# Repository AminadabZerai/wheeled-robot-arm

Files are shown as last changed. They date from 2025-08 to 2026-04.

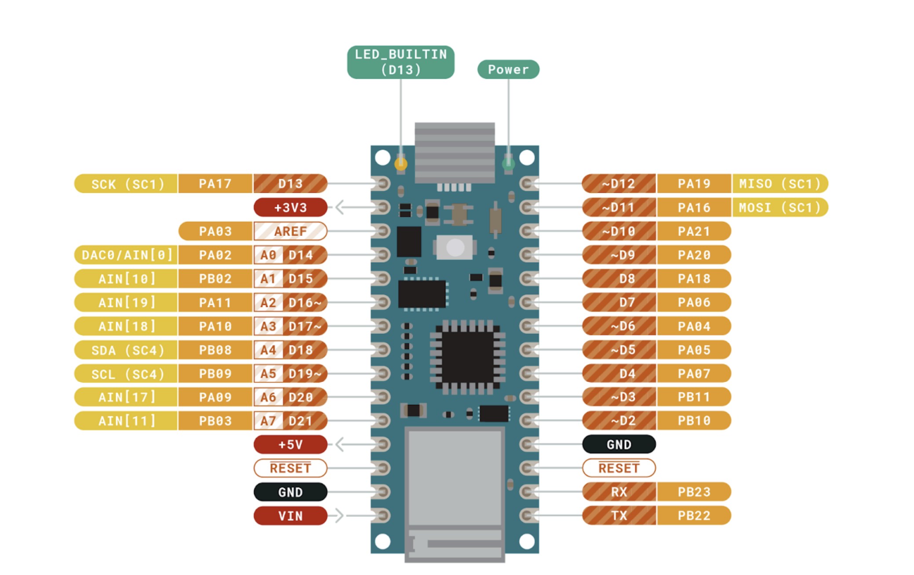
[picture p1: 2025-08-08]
Roadmap and Reference/Pinouts/Screenshot 2025-07-16 204437.jpg

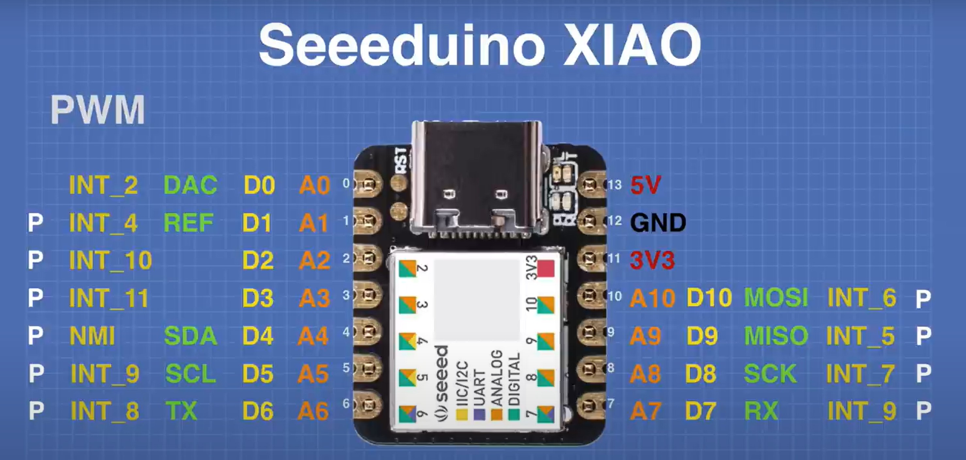
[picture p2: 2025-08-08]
Roadmap and Reference/Pinouts/Screenshot 2025-07-22 153515.jpg

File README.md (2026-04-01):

# wheeled-robot-arm

Wheeled robot with manipulator arm — ROS 2, Arduino, Raspberry Pi

A modular robotics platform combining a 4-wheel mecanum base with an articulated
manipulator arm. Built using Raspberry Pi, ROS 2, Arduino Nano 33 IoT, and custom
electronics. Designed for research, education, and portfolio development.

## Table of Contents

- [About](#about)
- [System Architecture](#system-architecture)
- [Project Roadmap](#project-roadmap)
- [Hardware](#hardware)
- [Software](#software)
- [Repository Structure](#repository-structure)
- [Getting Started](#getting-started)
- [Documentation](#documentation)
- [Contributing](#contributing)
- [License](#license)

## About

This project aims to design and build a wheeled mobile robot equipped with a
manipulator arm. It combines mechanical design, electronics, embedded systems,
and high-level control using ROS 2.

The firmware follows a component-based architecture — each hardware subsystem
(IMU, encoders, motors, PID) is isolated into its own driver module with a
clean API, making the system testable, swappable, and maintainable.

## System Architecture
```
┌─────────────────────────────────────┐
│         Raspberry Pi (ROS 2)        │
│   Navigation · Planning · Comms     │
└──────────────┬──────────────────────┘
               │ Serial / USB
┌──────────────▼──────────────────────┐
│       Arduino Nano 33 IoT          │
│  Main controller — 100Hz loop      │
│                                     │
│  ┌─────────┐ ┌──────────────────┐  │
│  │ LSM6DS3 │ │   TCA9548A Mux   │  │
│  │  IMU    │ │   ┌──┐┌──┐┌──┐┌──┐ │
│  └─────────┘ │   │E1││E2││E3││E4│ │
│              │   └──┘└──┘└──┘└──┘ │
│              │   AS5600 Encoders  │  │
│              └──────────────────────┘│
│  ┌──────────────────────────────┐   │
│  │  TB6612FNG Motor Drivers ×2  │   │
│  │  4× DC Motors (7.4V LiPo)   │   │
│  └──────────────────────────────┘   │
└─────────────────────────────────────┘
```

**Key design decisions:**
- Single MCU (Arduino Nano 33 IoT) controls all 4 wheels instead of per-wheel MCUs
- TCA9548A I2C multiplexer allows 4× AS5600 encoders on the same bus (same address 0x36)
- IMU (LSM6DS3) shares the I2C bus for orientation sensing
- PID + feedforward velocity control runs at 50 Hz per motor
- MATLAB tooling for offline calibration and sensor characterization

## Project Roadmap

### ✅ Section 1: Motor, Encoder, and Odometry Setup
- [x] Power system setup (7.4V LiPo, buck converters)
- [x] Mechanical assembly and wiring validation
- [x] AS5600 encoder integration via TCA9548A I2C mux
- [x] TB6612FNG motor driver wiring (2× drivers, 4 motors)
- [x] PID + feedforward velocity control (tuned, proven baseline)
- [x] Basic serial command interface (`f,150` / `r,90`)

### 🔄 Section 1.5: Firmware Refactoring & Sensor Characterization *(current)*
- [x] IMU driver extraction (`lib/IMU/`)
- [x] LSM6DS3 calibration and characterization (PASS — see journal)
- [x] MATLAB real-time plotter, 3D visualizer, and analysis tooling
- [x] Development journal established (`docs/journal.md`)
- [ ] Fix sampling jitter (interrupt-driven reads)
- [ ] AS5600 driver refactoring to match IMU module pattern
- [ ] Motor/PID module extraction
- [ ] Config/pin definitions centralized (`include/config.h`)
- [ ] On-board complementary filter for orientation

### 🔜 Section 2: Motion Control & Odometry
- [ ] Mecanum kinematic model (wheel velocities ↔ robot twist)
- [ ] Odometry estimation from encoders + IMU fusion
- [ ] Serial protocol for ROS 2 bridge (velocity commands + odom feedback)

### 🔜 Section 3: Manipulator Arm Integration
- [ ] Arm kinematics and mechanical design
- [ ] Servo/stepper driver electronics
- [ ] Dedicated controller or shared bus for arm joints
- [ ] ROS 2 nodes for arm control and planning

### 🔜 Section 4: High-Level Integration
- [ ] Raspberry Pi ROS 2 orchestration
- [ ] Autonomous and manual control modes
- [ ] System-level testing and refinement

## Hardware

| Component | Role | Qty |
|---|---|-----|
| Arduino Nano 33 IoT | Main MCU (3.3V logic) | 1 |
| Raspberry Pi | High-level ROS 2 control | 1 |
| AS5600 | 12-bit magnetic encoder | 4 |
| TCA9548A | I2C multiplexer | 1 |
| TB6612FNG | Dual H-bridge motor driver | 2 |
| DC Motors | Mecanum wheels, 7.4V | 4 |
| LiPo Battery | 7.4V 2S | 1 |
| Buck Converters | Voltage regulation | as needed |
| 3D Printed Parts | Brackets, mounts, chassis | various |

## Software

**Firmware (Arduino)**
- Modular C/C++ drivers in `lib/` (IMU, AS5600, MotorWheel, PID)
- 100 Hz deterministic main loop
- PID + feedforward velocity control with anti-windup
- Machine-readable CSV telemetry output

**MATLAB Tooling**
- Real-time data acquisition with infinite streaming and CSV export
- 3D orientation visualization with complementary filter
- Post-capture statistical analysis (noise, PSD, bias, pass/fail)

**ROS 2 (planned)**
- Velocity command interface
- Odometry publisher
- Arm control nodes

## Repository Structure
```
WHEELED-ROBOT-ARM/
├── src/
│   └── main.cpp              # Main firmware
├── include/
│   └── config.h              # Pin definitions and constants
├── lib/
│   ├── IMU/                  # LSM6DS3 driver
│   ├── AS5600/               # Magnetic encoder driver
│   ├── MotorWheel/           # Motor control abstraction
│   ├── PID/                  # PID controller
│   └── MoveBase/             # Kinematics and motion
├── matlab/
│   ├── imu_calibration_and_data.m
│   ├── imu_3d_visualization.m
│   ├── imu_analysis.m
│   └── data/                 # CSV captures
├── docs/
│   └── journal.md                        # Development journal
    └── zerillio_procedures.md            # General Procedure to boot the raspberry pi 3
├── 3D Files/                             # CAD and printable parts
├── Datasheets/                           # Component datasheets
├── ros2_ws/                              # ROS 2 workspace (future)
├── platformio.ini
├── LICENSE
└── README.md
```

## Getting Started

### Prerequisites
- [PlatformIO](https://platformio.org/) (firmware build and upload)
- MATLAB R2020b+ with Signal Processing Toolbox (analysis scripts)
- Arduino Nano 33 IoT board support

### Flash the firmware
```bash
cd WHEELED-ROBOT-ARM
pio run -t upload
```

### Run MATLAB live plotter
1. Connect Arduino via USB
2. Update `port` in the script to match your COM port
3. Run `imu_calibration_and_data.m`
4. Close the figure window to stop — CSV saves automatically

## Documentation

See [`docs/journal.md`](./docs/journal.md) for detailed development logs including
sensor characterization results, architecture decisions, and test data.

Additional resources in [`Datasheets/`](./Datasheets) and
[`Roadmap and References/`](./Roadmap%20and%20References).

## Contributing

Contributions, ideas, and bug reports are welcome.
Please open an Issue or submit a Pull Request.

## License

This project is licensed under the MIT License. See [LICENSE](./LICENSE) for details.

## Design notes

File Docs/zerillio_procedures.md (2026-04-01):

# Zerillio - Raspberry Pi 3 B+ Quick Reference

## Connection Info

- **Hostname:** zerillio.local
- **IP (hotspot):** check with `arp -a` from your PC (changes each time)
- **Username:** pi3
- **SSH command:** `ssh pi3@zerillio.local` or `ssh pi3@<IP_ADDRESS>`

---

## Starting Up

1. Make sure your phone hotspot is ON and broadcasting
2. Plug in the power cable to the Pi (there is no power button)
3. Wait ~2 minutes for boot + Wi-Fi connection
4. Check your phone — it should show a new connected device
5. From your PC (on the same hotspot), open Tabby or PowerShell:
   ```
   ssh pi3@zerillio.local
   ```
6. If hostname doesn't resolve:
   ```
   arp -a
   ```
   Find the Pi's IP and connect with `ssh pi3@<IP>`

---

## Shutting Down (Graceful)

Always shut down gracefully to avoid SD card corruption:

```
sudo shutdown -h now
```

Wait about 10 seconds until the green LED stops blinking, then unplug the power cable.

### Other Shutdown Options

| Command | What it does |
|---|---|
| `sudo shutdown -h now` | Shutdown immediately |
| `sudo shutdown -h +5` | Shutdown in 5 minutes |
| `sudo poweroff` | Same as shutdown -h now |
| `sudo reboot` | Restart the Pi |

---

## NEVER DO THIS

- **Never just unplug the power cable** while the Pi is running — this can corrupt the SD card and break your OS/ROS installation

---

## Useful Commands Once Connected

| Command | What it does |
|---|---|
| `htop` | Monitor CPU/RAM usage |
| `df -h` | Check disk space |
| `vcgencmd measure_temp` | Check CPU temperature |
| `tmux` | Start a persistent terminal session |
| `tmux attach` | Reattach to a tmux session after disconnect |
| `ros2 doctor` | Check ROS 2 health |
| `source ~/.bashrc` | Reload shell config |

---

## Wi-Fi Networks Configured

1. **ABI24** (phone hotspot) — primary, SSH works
2. **eduroam** (Polito) — internet only, SSH blocked by network

---

## ROS 2 Info

- **Distro:** Jazzy Jalisco
- **Workspace:** ~/ros2_ws/src
- **Domain ID:** 42
- **Robot name:** zerillio

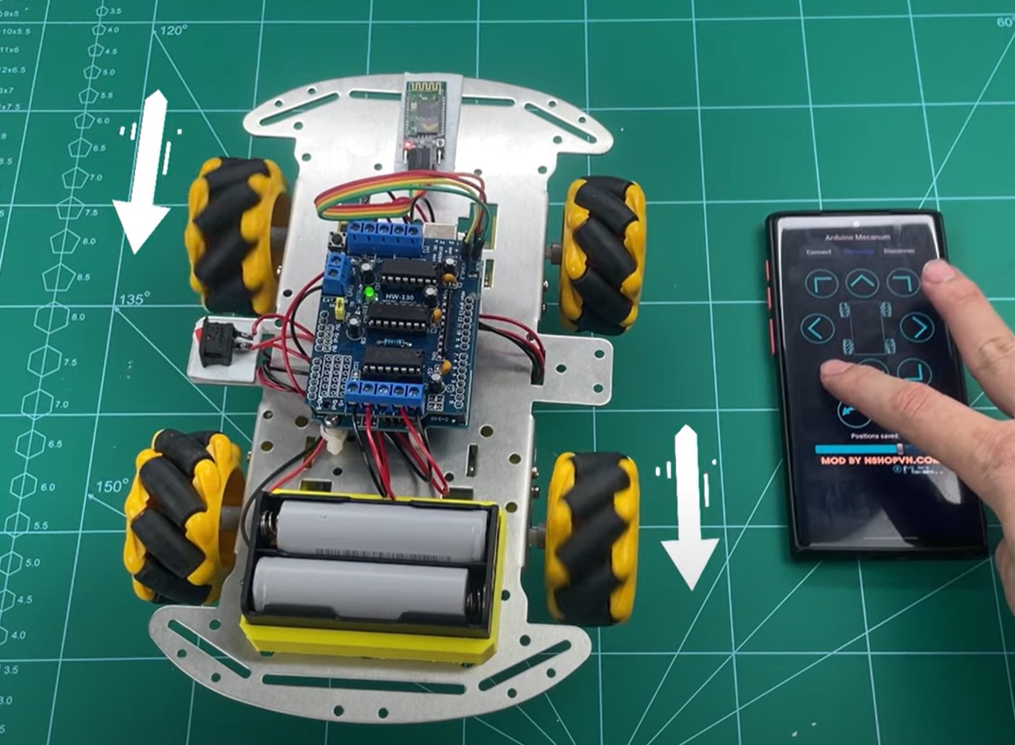
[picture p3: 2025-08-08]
Roadmap and Reference/Mecanum_Wheel_Control/Mecanum_Wheel_DIAG_LB.jpg

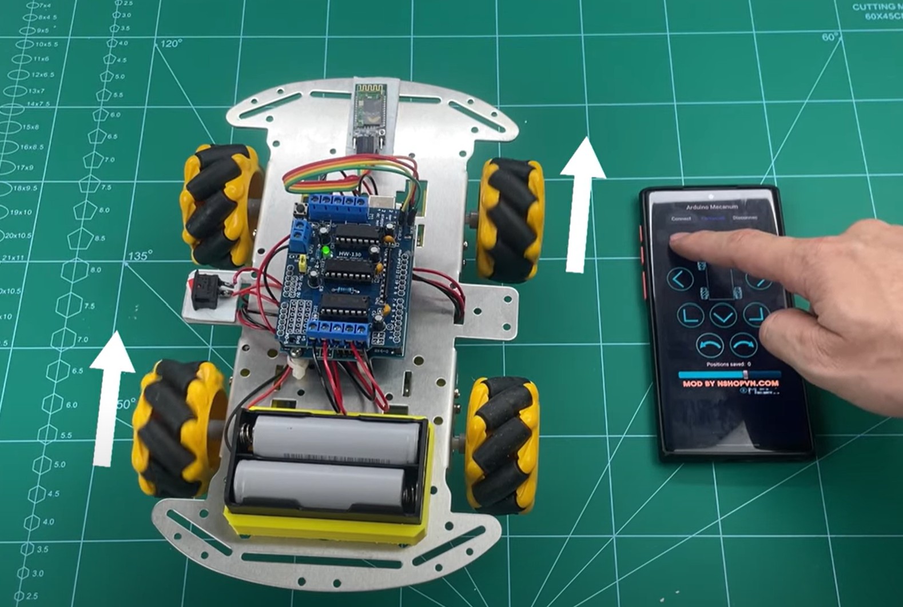
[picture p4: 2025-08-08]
Roadmap and Reference/Mecanum_Wheel_Control/Mecanum_Wheel_DIAG_LT.jpg

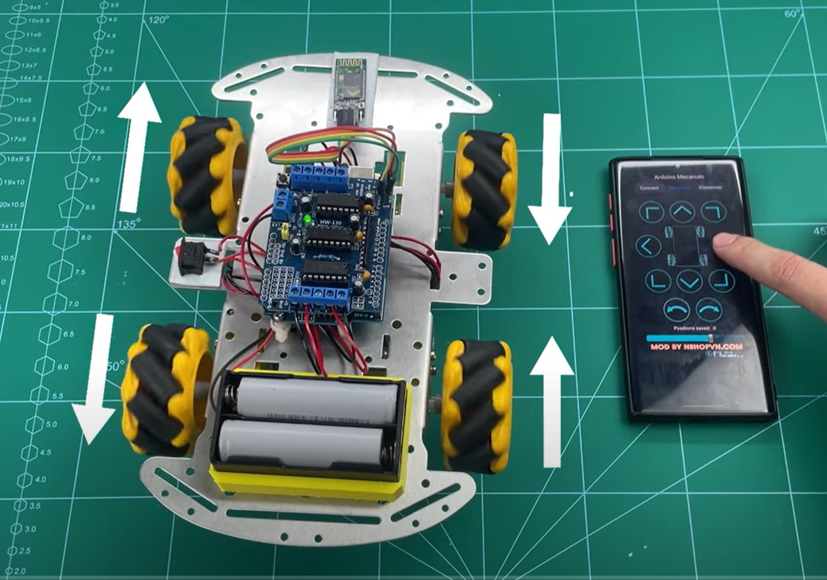
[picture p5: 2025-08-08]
Roadmap and Reference/Mecanum_Wheel_Control/Mecanum_Wheel_SW_R.jpg

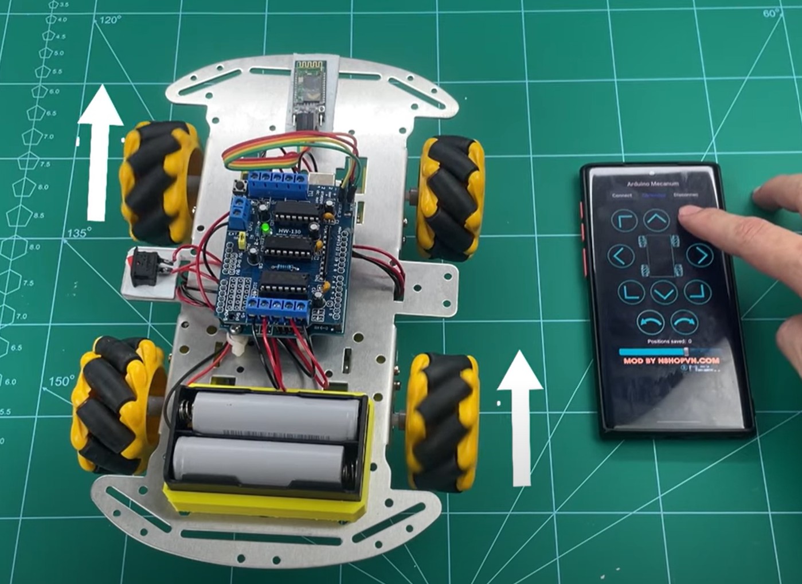
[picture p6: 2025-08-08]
Roadmap and Reference/Mecanum_Wheel_Control/Mecanum_Wheel_DIAG_RT.jpg

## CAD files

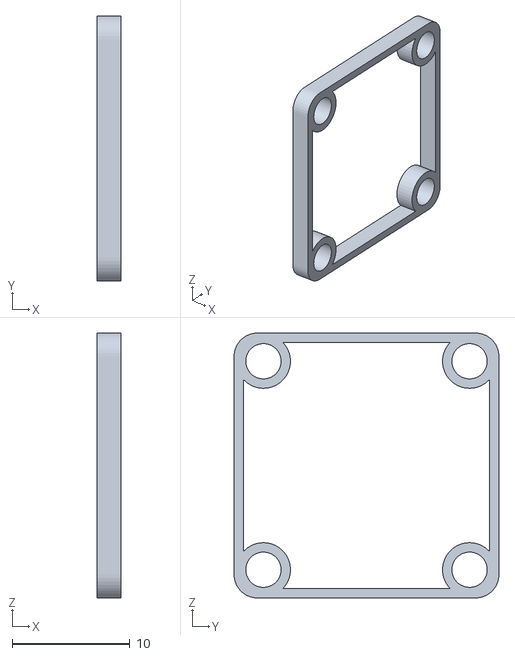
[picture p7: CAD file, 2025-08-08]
3D Files/Final_Brack_Assembly_Iteration_1 - AS5600_Bracket_Iteration_1-1.STL
2.00 x 22.5 x 22.5

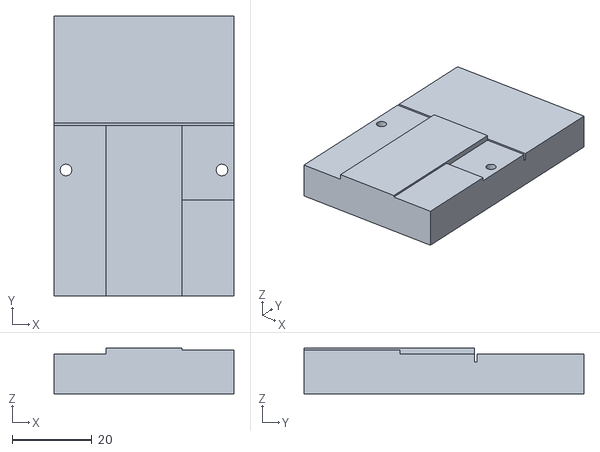
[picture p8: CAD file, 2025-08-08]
3D Files/Final_Brack_Assembly_Iteration_1 - Bracket_Base_Iteration_4-1.STL
45.0 x 70.0 x 11.5

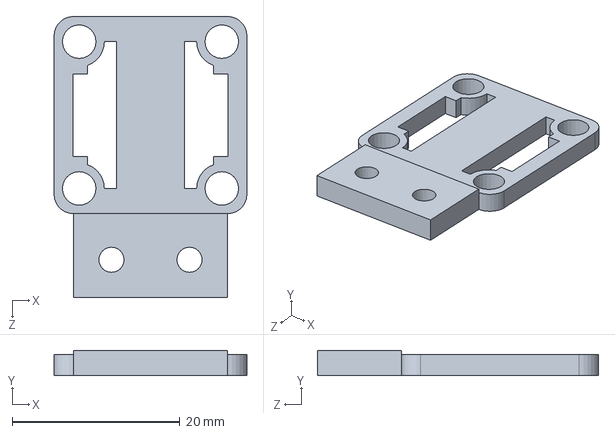
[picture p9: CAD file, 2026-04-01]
3D Files/AS5600_Bracket_Iteration_12.SLDPRT
23.0 x 3.00 x 33.5 mm

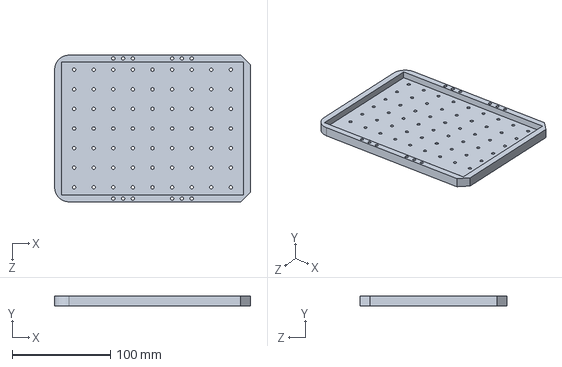
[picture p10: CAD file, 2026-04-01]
3D Files/Chasis_Holed_Iteration_1.SLDPRT
200.0 x 10.0 x 150.0 mm

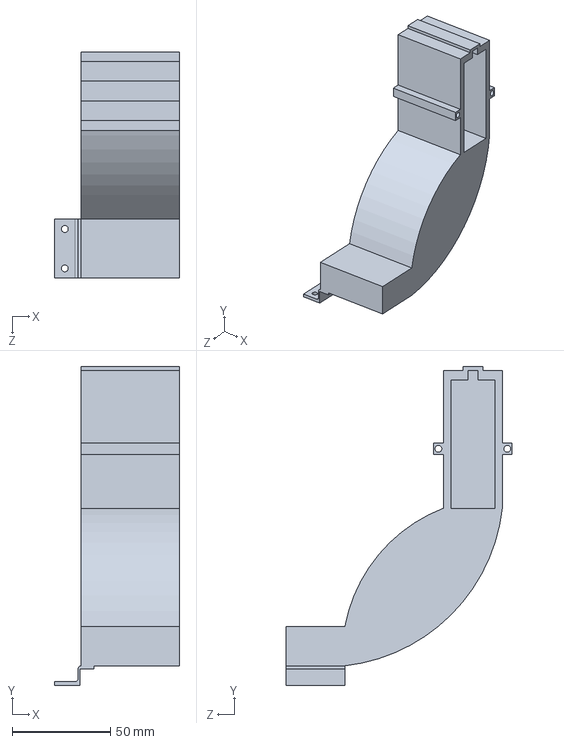
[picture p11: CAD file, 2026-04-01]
3D Files/Wheel_Leg_Iteration_1.SLDPRT
63.5 x 162.0 x 115.0 mm

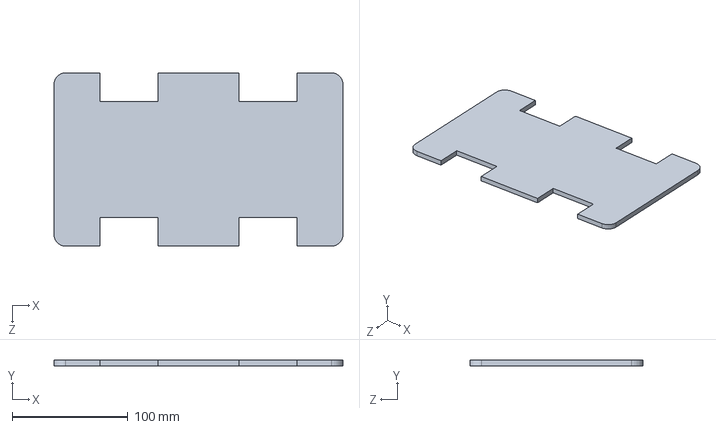
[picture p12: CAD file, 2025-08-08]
3D Files/Chasis_Iteration_1.SLDPRT
250.0 x 5.00 x 150.0 mm

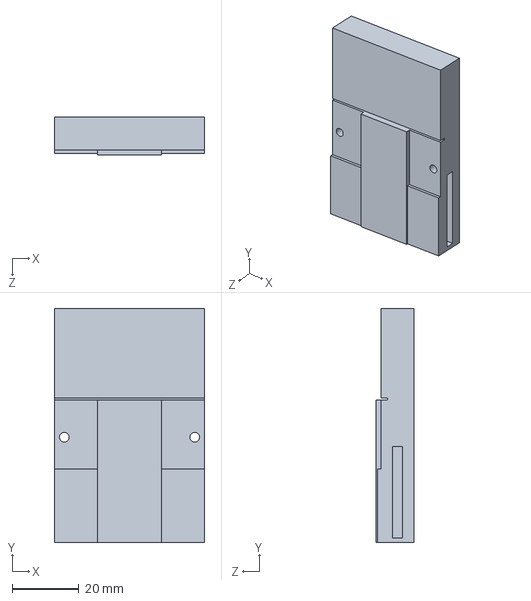
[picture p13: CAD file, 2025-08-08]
3D Files/Bracket_Base_Iteration_8.SLDPRT
45.0 x 70.0 x 11.5 mm

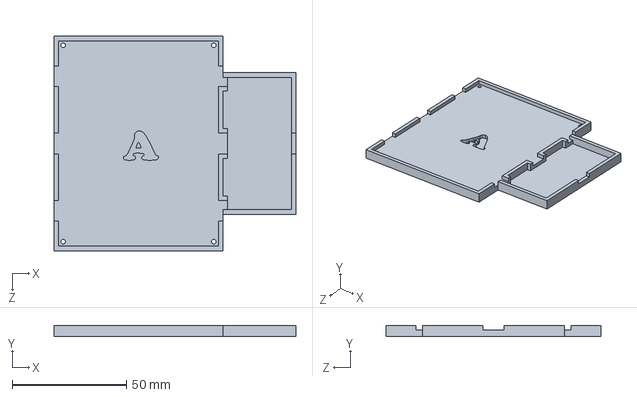
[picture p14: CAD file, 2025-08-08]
3D Files/Power_Management.SLDPRT
106.0 x 5.00 x 94.0 mm

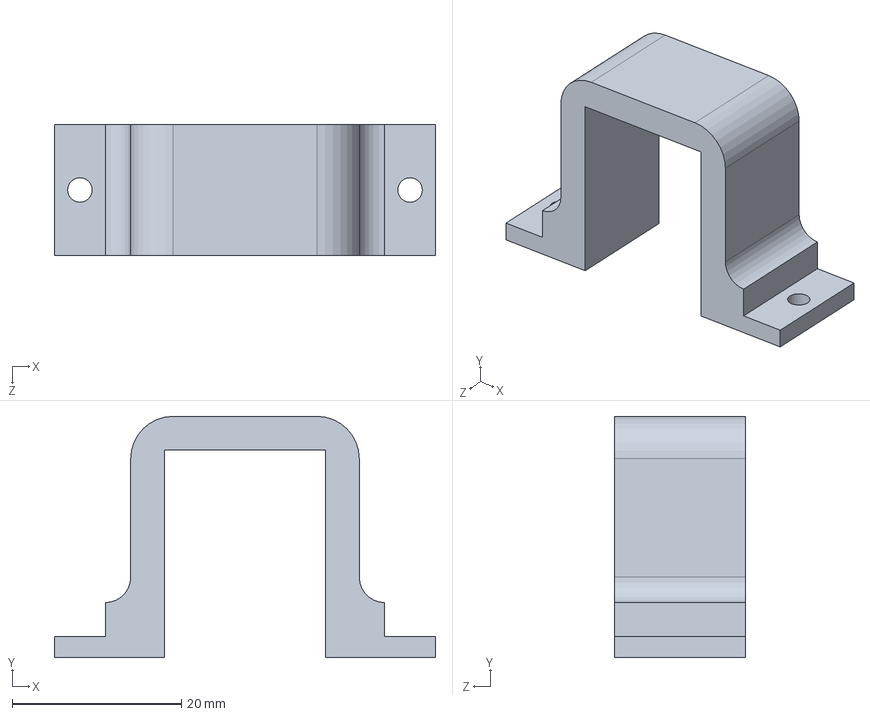
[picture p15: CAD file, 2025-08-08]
3D Files/Motor_Bracket_Iteration_8.SLDPRT
45.0 x 28.5 x 15.5 mm

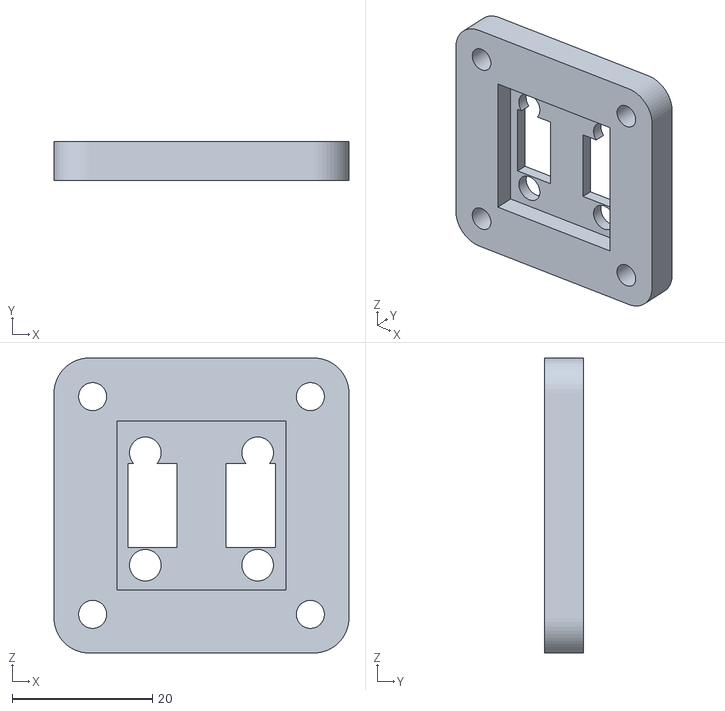
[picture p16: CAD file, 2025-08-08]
3D Files/AS5600Mount_nema17.stl
42.0 x 5.50 x 42.0

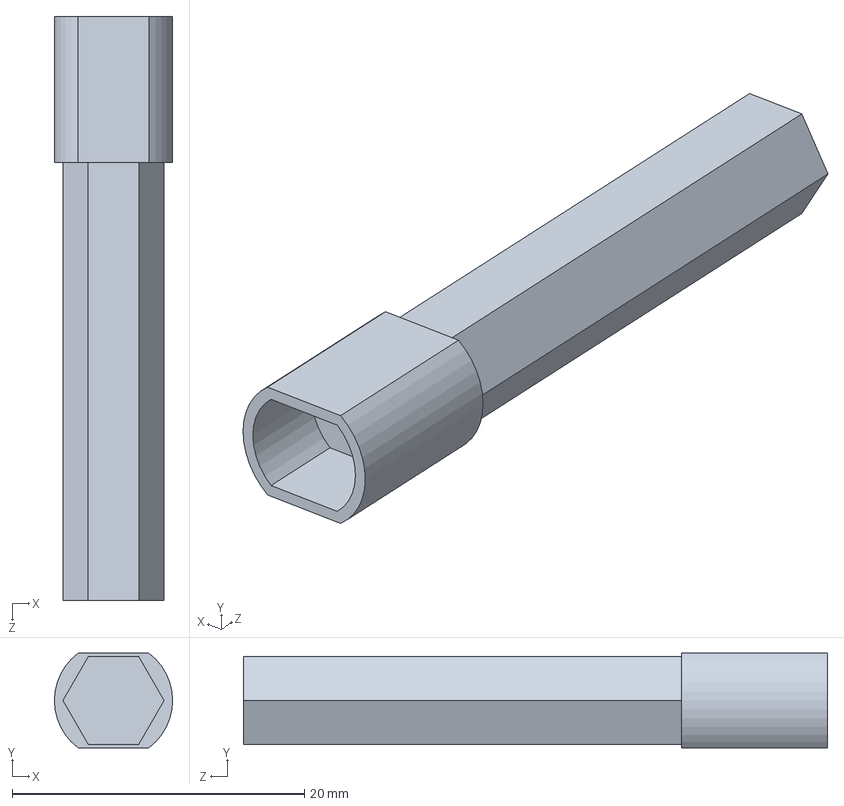
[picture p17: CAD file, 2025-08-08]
3D Files/Wheel_shaft_Iteration_5.SLDPRT
8.10 x 6.50 x 40.0 mm

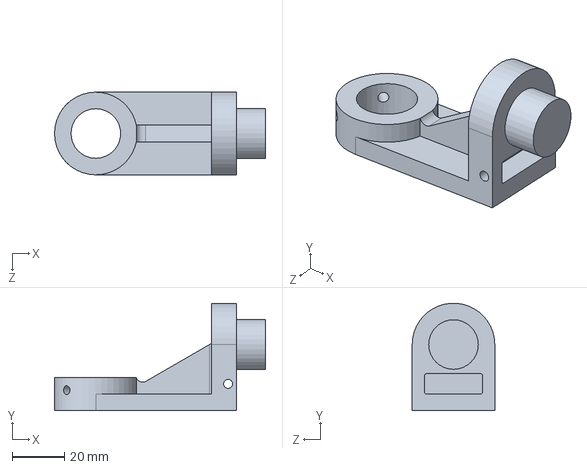
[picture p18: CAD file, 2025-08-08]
3D Files/cswa_practice_YT_1.SLDPRT
81.0 x 41.2 x 31.8 mm

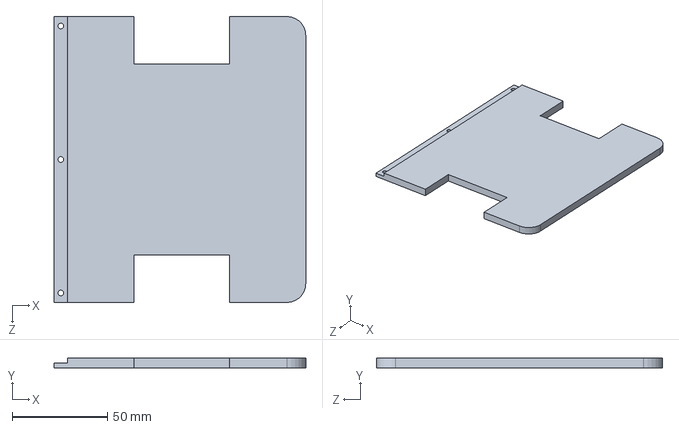
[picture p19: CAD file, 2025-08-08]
3D Files/Chasis_Iteration_2_prt_1.SLDPRT
132.0 x 5.00 x 150.0 mm

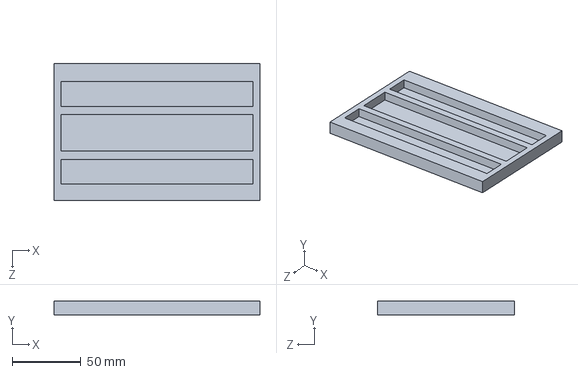
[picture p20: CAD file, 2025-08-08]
3D Files/Base_Plank.SLDPRT
150.0 x 10.0 x 100.0 mm

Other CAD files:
3D Files/Final_Brack_Assembly_Iteration_1.SLDASM
3D Files/AS5600_Bracket_Iteration_6.SLDPRT
3D Files/Motor_Bracket_Iteration_2.SLDPRT
3D Files/Motor_Bracket_Iteration_1.SLDPRT
3D Files/AS5600_Bracket_Iteration_1.SLDPRT
3D Files/AS5600_Bracket_Iteration_1.STL
3D Files/AS5600_Bracket_Iteration_10.SLDPRT
3D Files/AS5600_Bracket_Iteration_10.STL
3D Files/AS5600_Bracket_Iteration_11.SLDPRT
3D Files/AS5600_Bracket_Iteration_11.STL
3D Files/AS5600_Bracket_Iteration_12.STL
3D Files/AS5600_Bracket_Iteration_2.SLDPRT
3D Files/AS5600_Bracket_Iteration_3.SLDPRT
3D Files/AS5600_Bracket_Iteration_3.STL
3D Files/AS5600_Bracket_Iteration_4.SLDPRT
3D Files/AS5600_Bracket_Iteration_4.STL
3D Files/AS5600_Bracket_Iteration_5.SLDPRT
3D Files/AS5600_Bracket_Iteration_5.STL
3D Files/AS5600_Bracket_Iteration_6.STL
3D Files/AS5600_Bracket_Iteration_7.SLDPRT
3D Files/AS5600_Bracket_Iteration_7.STL
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

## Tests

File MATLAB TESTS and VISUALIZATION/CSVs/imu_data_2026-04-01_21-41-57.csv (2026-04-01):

Time_s | AccX | AccY | AccZ | GyrX | GyrY | GyrZ
0.892479 | 0.000000 | -6.000000 | 16381.000000 | 0.000000 | -57.000000 | 12.000000
0.899351 | 9.000000 | -6.000000 | 16391.000000 | 16.000000 | -47.000000 | 14.000000
0.907468 | 22.000000 | -6.000000 | 16384.000000 | -15.000000 | 2.000000 | -4.000000
0.923280 | -3.000000 | -9.000000 | 16369.000000 | 1.000000 | 10.000000 | -7.000000
0.925898 | -5.000000 | 1.000000 | 16374.000000 | -20.000000 | 58.000000 | -31.000000
0.983077 | 3.000000 | -17.000000 | 16381.000000 | 6.000000 | 65.000000 | -15.000000
0.984157 | -5.000000 | -18.000000 | 16373.000000 | -43.000000 | 70.000000 | -24.000000
0.984823 | 0.000000 | -9.000000 | 16401.000000 | -33.000000 | 40.000000 | -6.000000
0.985301 | 16.000000 | -9.000000 | 16391.000000 | -55.000000 | 48.000000 | -3.000000
0.985843 | 1.000000 | 12.000000 | 16380.000000 | -51.000000 | 28.000000 | 5.000000
0.986312 | -1.000000 | 1.000000 | 16404.000000 | -55.000000 | 59.000000 | 2.000000
0.987606 | 5.000000 | 5.000000 | 16373.000000 | -33.000000 | 41.000000 | 2.000000
0.998878 | 0.000000 | 10.000000 | 16401.000000 | -67.000000 | 96.000000 | 3.000000
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

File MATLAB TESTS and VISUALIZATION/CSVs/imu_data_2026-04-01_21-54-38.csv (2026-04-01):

Time_s | AccX | AccY | AccZ | GyrX | GyrY | GyrZ
0.012894 | -113.000000 | -270.000000 | 16378.000000 | -10.000000 | 14.000000 | 23.000000
0.268152 | -123.000000 | -285.000000 | 16386.000000 | -39.000000 | 14.000000 | -2.000000
0.269679 | -127.000000 | -292.000000 | 16367.000000 | 3.000000 | -14.000000 | 2.000000
0.270860 | -143.000000 | -300.000000 | 16360.000000 | -14.000000 | 38.000000 | 3.000000
0.273396 | -123.000000 | -276.000000 | 16360.000000 | 10.000000 | -13.000000 | 3.000000
0.276114 | -109.000000 | -287.000000 | 16386.000000 | 30.000000 | -28.000000 | 13.000000
0.276754 | -110.000000 | -247.000000 | 16354.000000 | 32.000000 | -3.000000 | 41.000000
0.277171 | -101.000000 | -238.000000 | 16390.000000 | 21.000000 | -30.000000 | 13.000000
0.277577 | -83.000000 | -216.000000 | 16349.000000 | 24.000000 | -54.000000 | 3.000000
0.277991 | -65.000000 | -237.000000 | 16392.000000 | 20.000000 | -43.000000 | 14.000000
0.278355 | -80.000000 | -220.000000 | 16352.000000 | 20.000000 | -47.000000 | 11.000000
0.278783 | -69.000000 | -241.000000 | 16364.000000 | -9.000000 | -19.000000 | -2.000000
0.279126 | -90.000000 | -236.000000 | 16357.000000 | -3.000000 | 27.000000 | 5.000000
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

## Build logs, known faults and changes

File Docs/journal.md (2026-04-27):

# Development Journal

---

## 2026-04-01 — IMU Calibration Testing & Architecture Refactoring

### Overview
Two major milestones today: (1) completed the first full IMU characterization session
for the LSM6DS3, with MATLAB tooling for real-time acquisition, 3D visualization, and
statistical analysis; (2) began the architectural refactoring of the firmware from a
monolithic "god-file" into a modular, component-based system.

---

### Part 1: IMU Calibration & Characterization

#### Test Setup
- Sensor: LSM6DS3 (I2C @ 100 kHz)
- MCU: Arduino Nano 33 IoT (Serial @ 115200 baud)
- Sampling: 100 Hz target (10 ms interval)
- Calibration: 10-second stationary window at startup
- Capture: ~100 seconds, 10,030 samples
- Condition: Sensor flat on desk, stationary throughout

#### Results Summary

**Accelerometer**

| Metric | X | Y | Z |
|---|---|---|---|
| Mean | +0.0000 g | -0.0001 g | +1.0003 g |
| Std | 0.0005 g | 0.0005 g | 0.0006 g |
| Noise Density | 0.0001 g/√Hz | 0.0000 g/√Hz | 0.0001 g/√Hz |

- Magnitude: 1.0003 g mean, 0.0006 g std (ideal = 1.0000 g)
- Verdict: **PASS** — Bias negligible, magnitude stable

**Gyroscope**

| Metric | X | Y | Z |
|---|---|---|---|
| Bias | +0.005 °/s | -0.006 °/s | -0.010 °/s |
| Std | 0.107 °/s | 0.096 °/s | 0.089 °/s |
| Noise Density | 0.0107 (°/s)/√Hz | 0.0096 (°/s)/√Hz | 0.0089 (°/s)/√Hz |
| 60s Drift | 0.31° | 0.38° | 0.63° |

- Verdict: **PASS** — All bias values well under 1 °/s

**Pass/Fail Checklist**

| Check | Threshold | Result |
|---|---|---|
| Accel XY bias | < 0.05 g | **PASS** |
| Accel Z offset from 1g | < 0.05 g | **PASS** |
| Accel magnitude | ~1.000 g | **PASS** (1.0003 g) |
| Gyro bias all axes | < 1 °/s | **PASS** |

#### Observations & Concerns

1. **Sampling Jitter (Critical)**
   dt std = 24.8 ms, jitter = 204 ms peak, 1,164 missed samples (11.6%).
   Root cause: `Serial.print` blocking and/or I2C read latency in the main loop.
   This is the #1 issue to fix before motor integration — inconsistent dt corrupts
   gyro integration and will cause drift in orientation estimates.
   - Reading 14 bytes (6 Accel, 6 Gyro, 2 Temp) plus I2C overhead takes approximately 1.5ms to 2ms per cycle at 100 kHz. When combined with Serial.print (which takes ~3–5ms for a long CSV string at 115200 baud), you are consuming nearly 70% of your 10ms window just on I2C and Serial comms.
   Possible Action: move to Wire.setClock(400000); to reclaim overhead for the PID math.

2. **Noise Distribution**
   - Acc X and Gyr X: Very tight, narrow Gaussian — lowest noise axes.
   - Acc Y and Gyr Y: Clean Gaussian, slightly wider — normal.
   - Acc Z: Wider with slight asymmetry — expected for Z-axis MEMS structure.
   - Gyr Z: Ragged, non-ideal shape — may indicate vibration or mounting issue.
     Monitor this once mounted on the chassis.

3. **Power Spectral Density**
   - Accelerometer: Low-frequency energy at 3–5 Hz (environmental vibration).
     Visible as slow "breathing" envelope in the magnitude stability plot.
   - Gyroscope: Rising energy toward 50 Hz — likely mains interference (Italy = 50 Hz).
     Action: keep IMU wiring short and routed away from motor power lines.

4. **Magnitude Stability**
   Accel magnitude holds steady at 1.0003 ± 0.0006 g over the full 100s capture.
   Translates to ~±0.05° tilt uncertainty — more than sufficient for robot orientation.

#### Key Numbers for Future Filter Tuning

These noise density values become the Q/R covariance entries when implementing
a Kalman or complementary filter:

| Parameter | X | Y | Z | Unit |
|---|---|---|---|---|
| Accel noise density | 0.0001 | 0.0000 | 0.0001 | g/√Hz |
| Gyro noise density  | 0.0107 | 0.0096 | 0.0089 | (°/s)/√Hz |
| Gyro bias | +0.005 | -0.006 | -0.010 | °/s |

---

### Part 2: Architecture Refactoring

#### The Problem: "God-File" Spaghetti

The previous `main.cpp` contained everything — I2C bus management, register-level
bit manipulation, calibration math, PID control for 4 motors, encoder reading,
serial telemetry, and command parsing — all in a single ~500-line file. The code
was tightly coupled: changing the serial output format could accidentally break
I2C timing. Adding a new sensor meant copy-pasting dozens of lines, doubling the
surface area for bugs.

#### The Solution: Component-Based Architecture

We are transitioning from *imperative spaghetti* (a list of instructions for the CPU)
to *component-based architecture* (a collection of services for the robot).

**Phase 1 — Decoupling the Hardware (Driver Layer)**

Extracted LSM6DS3 logic into `imu.h` / `imu.cpp`, creating an abstraction layer.
`main.cpp` no longer needs to know that gyroscope data starts at register `0x22` —
it calls `lsm6ds3_read_gyro()`. The sensor's identity (address, offsets, status)
is packaged into a struct (`lsm6ds3_t`), which is the foundation of object-oriented
thinking in a C environment.

-By passing the sensor struct as a pointer to every function (e.g., lsm6ds3_read_accel(&imu, ...)), we avoided "Hardcoding" the sensor. This makes the driver Reentrant. If you decide to add a second IMU for safety, you simply declare lsm6ds3_t imu2; and use the same functions.

We hit a "language identity crisis" where the C compiler couldn't read Arduino's
C++ libraries. Solved by renaming to `.cpp` and wrapping with `extern "C"` — keeping
the cleanliness of C function interfaces while using C++ hardware libraries.

**Phase 2 — Implementing a Contract (The API)**

By defining strict function prototypes in the header file, `main.cpp` becomes a
*client* that only cares *what* the functions do (init, read, calibrate), while
`imu.cpp` is the *provider* that handles *how*. If we swap the LSM6DS3 for an
MPU-6050 tomorrow, only the provider changes — `main.cpp` stays untouched because
the contract is the same.

**Phase 3 — Deterministic Execution (The Heartbeat)**

Refactored from "run as fast as possible" to a 10 ms deterministic loop using
`millis()`. Moved serial output from chatty labeled text to machine-readable CSV,
separating the firmware's role (data source) from MATLAB's role (data analyst).

#### Module Roadmap

| Module | Files | Status |
|---|---|---|
| IMU Driver | `lib/IMU/imu.h`, `imu.cpp` | ✅ Complete |
| AS5600 Encoder | `lib/AS5600/as5600.h`, `as5600.c` | 🔄 Next — needs same refactor |
| Motor Control | `lib/MotorWheel/` | 📋 Planned |
| PID Controller | `lib/PID/` | 📋 Planned |
| Move Base | `lib/MoveBase/` | 📋 Planned |
| Config / Pins | `include/config.h` | 🔄 Started |
| Main State Machine | `src/main.cpp` | 🔄 In progress |

#### Impact

This refactor reduced `main.cpp` complexity by ~60%, moved hardware-specific
"magic numbers" into isolated drivers, and established the 100 Hz deterministic
heartbeat required for stable PID control.

- Technical Debt Paydown: > Before today, the "Cost of Change" was high—adding a feature required a full-file audit.
After today, we have Separation of Concerns. The IMU is a "Black Box" that provides a stream of floats. This isolation is what will allow us to scale to 4-wheel independent PID control without the code becoming unmanageable.

---

### Files Added This Commit
```
docs/journal.md                              — This file
matlab/imu_calibration_and_data.m            — Live plotter with CSV export
matlab/imu_3d_visualization.m                — Real-time 3D orientation viewer
matlab/imu_analysis.m                        — Post-capture statistical analysis
matlab/data/imu_data_2026-04-01_22-10-42.csv — Raw calibration capture
```

### Next Steps

- [ ] Fix sampling jitter — move to interrupt-driven IMU reads or reduce Serial blocking
- [ ] Refactor AS5600 encoder driver to match IMU module pattern
- [ ] Run IMU vibration test with motors on to characterize noise under load
- [ ] Implement on-board complementary filter (Arduino side)
- [ ] Extract motor control into `MotorWheel` module
- [ ] Extract PID into reusable `PID` module (per-motor instances)

--------------------------------------------------------------------------------------------------------------------------------------------------------------------------------------------------------------

## 2026-04-02 — I2C Multiplexing, Encoder Integrity & Hardware POST Implementation

### Overview
Three major threads today: (1) implemented a modular Power-On Self-Test (POST)
framework for hardware safety validation; (2) resolved I2C address collisions using
the TCA9548A multiplexer, including a critical bitmask bug; and (3) advanced the
AS5600 encoder driver toward PID-ready telemetry. The robot now performs a "medical
exam" before entering the control loop and has a clean, validated hardware backbone.

---

### Part 1: Hardware Integrity & POST (Power-On Self-Test)

#### The Strategy: "Safety First" Bootloader

To prevent mechanical runaway on startup, we implemented a modular `post.cpp`
library. Before entering the main control loop, the robot performs a structured
hardware health check — if any sensor reports a sub-optimal condition, the system
enters an **SOS Blink** halt state with a specific diagnostic message rather than
attempting to run.

#### Key Implementations

**Magnetic Field Validation**
Created `post_as5600_health()` to monitor the Status register (`0x0B`) and the
Automatic Gain Control register (`0x1A`). The system distinguishes between a missing
magnet and an air-gap that is too wide, surfacing specific failure strings such as:
`[FAIL] Enc Left-Front - NO MAGNET`.

**Bus Presence Checks**
Before any driver initialisation, the POST verifies both the IMU and MUX are
acknowledging on the main I2C line.

**POST Results Summary**

| Component | Check | Threshold | Result |
|---|---|---|---|
| LSM6DS3 | WHO_AM_I | 0x69 | **PASS** |
| TCA9548A | I2C Probe | Ack @ 0x70 | **PASS** |
| AS5600 | Magnet Detected | MD Bit == 1 | **PASS** |
| AS5600 | Signal Strength | AGC < 200 | **PASS** |

---

### Part 2: I2C Multiplexing & Communication Logic

#### The Problem: Address Collision & "Ghost" Readings

All four AS5600 encoders share a fixed I2C address (`0x36`). The TCA9548A
multiplexer was introduced to isolate each encoder on its own channel. On first
integration, all four channels returned `65535` (2¹⁶ − 1). This was identified as
**"Floating High"** behaviour — the MCU was reading pull-up resistors because the
MUX gate was not actually opening.

#### The Fix: Bitmask Addressing

The TCA9548A control register expects a **bitmask byte**, not a channel index.
Writing a raw integer `0` disables all channels rather than selecting channel 0.

- **Incorrect:** `Wire.write(0);` — disables all channels
- **Correct:** `Wire.write(1 << MUX_CH_LF);` — opens only the target channel

This single-line correction eliminated all ghost readings.

---

### Part 3: MATLAB Integration & Telemetry Issues

#### Refactoring the Visualisation

Updated the MATLAB live-stream script to a **3-subplot layout** (Accelerometer,
Gyroscope, Encoder). The internal buffer was formalised to a strict **8-column
schema**: `[Time, Acc_X, Acc_Y, Acc_Z, Gyr_X, Gyr_Y, Gyr_Z, Encoder_Angle]`.

#### Current Blocker: Stream Stalling

Despite the Arduino transmitting data, MATLAB is not rendering the live stream.

**Root Cause (Suspected):** Data framing mismatch. The Arduino `loop()` was
emitting `raw_angle` on a separate `println`, producing a 6-value line followed by
a 1-value line. MATLAB's `readline()` sees an inconsistent column count and stalls.

**Fix (Pending):** Consolidate all 7 sensor values into a single
`Serial.print(...)` string terminated by one `\n`. This is the same principle as
the CSV framing fix from yesterday's session — one sample, one line, always.

---

### Module Status Roadmap

| Module | Files | Status |
|---|---|---|
| POST / System Health | `lib/POST/post.cpp` | ✅ Functional |
| IMU Driver | `lib/IMU/imu.cpp` | ✅ Stable |
| AS5600 Driver | `lib/AS5600/as5600.cpp` | 🔄 Hardware Test OK |
| MATLAB Tooling | `matlab/robot_live_stream.m` | ⚠️ Stalled (Framing Error) |

---

### Next Steps

- [x] **Finalise CSV Framing** — consolidate `Serial.print` in `main.cpp` to restore
      MATLAB live plotting; one line per sample, 8 columns, single `\n` terminator
- [x] **Rollover Math** — implement 12-bit → 32-bit "infinite rotation" accumulation
      logic in `as5600_update()` to handle multi-turn tracking without wrap-around jumps
- [x] **Angular Velocity** — derive rad/s from the encoder delta (Δangle / Δt) for
      use as the PID D-term input
- [ ] **Vibration Characterisation** — run IMU noise test with motors powered to
      measure the real-world noise floor under load (flagged from yesterday)

--------------------------------------------------------------------------------------------------------------------------------------------------------------------------------------------------------------

## 2026-04-03 — AS5600 Encoder Driver Completion, Toolchain Debugging & MATLAB Telemetry Suite

### Overview
Three major threads today: (1) diagnosed and resolved a PlatformIO library identity
conflict that was silently blocking the AS5600 driver from compiling; (2) completed
the full encoder driver implementation — infinite rotation tracking, MUX gating,
and velocity derivation — bringing the sensing layer to a synchronized, PID-ready
state; (3) designed and delivered a fully separated MATLAB telemetry and analysis
suite with four independent scripts covering IMU and encoder pipelines. The robot
now streams 8 channels of calibrated sensor data at 100 Hz with graceful session
management and clean CSV export.

---

### Part 1: PlatformIO Compilation Failure — Root Cause & Resolution

#### The Problem: Library Identity Conflict

On first build attempt, the compiler rejected every reference to `as5600_t` and
`as5600_init()` with the following error:

```
src\main.cpp:14:1: error: 'as5600_t' does not name a type; did you mean 'AS5600L'?
```

The suggested alternative `AS5600L` was the diagnostic key — PlatformIO had located
a community AS5600 library (robtillaart/AS5600) and was resolving all encoder
symbols against it instead of the custom driver. The custom header was being
silently ignored entirely.

#### Root Causes Identified

Two independent configuration errors in `platformio.ini` combined to produce the
failure:

**1. `lib_extra_dirs` exposed the entire Arduino library ecosystem**

```ini
lib_extra_dirs =
    C:/Users/Amine/Documents/Arduino/libraries
```

This gave PlatformIO's dependency scanner access to every installed Arduino library,
including the conflicting community AS5600 package.

**2. `lib_ldf_mode = deep` enabled aggressive symbol resolution**

With deep mode active, PlatformIO traverses all reachable directories looking for
any file that can satisfy an unresolved symbol. Combined with `lib_extra_dirs`,
this guaranteed the external library would be found and preferred over the local
driver — no warning, no error, just the wrong library silently winning.

#### The Fix

Stripped `platformio.ini` to the minimum viable configuration:

```ini
[env:nano33iot]
platform = atmelsam
board = nano_33_iot
framework = arduino
monitor_speed = 115200

build_flags =
    -Iinclude
```

External dependencies are now declared explicitly via `lib_deps` only, preventing
any implicit global library resolution. Build succeeded immediately on the next
attempt.

**Architectural Rule Established:** Never use `lib_extra_dirs` pointing to the
Arduino global library folder. This couples the build environment to machine-local
state and creates non-reproducible builds. Any dependency needed must appear in
`lib_deps` by name and version.

---

### Part 2: AS5600 Driver — Implementation & Hardening

#### A. The "Infinite Rotation" Engine — Rollover Math

**The Challenge:** The AS5600 is a 12-bit absolute encoder — its raw output resets
from 4095 back to 0 every 360°. A naive reading of this value would cause the PID
controller to perceive a massive instantaneous jump during every wheel revolution,
corrupting both the position error term and the derivative.

**The Fix:** A shortest-path displacement algorithm operating on signed 16-bit
arithmetic. Each control cycle computes the signed jump between the current and
previous raw angle, then applies a boundary correction:

```cpp
int16_t jump = sensor->last_raw_angle - previous_raw_angle;
if      (jump >  2048) jump -= 4096;  // Crossed 0-mark backwards
else if (jump < -2048) jump += 4096;  // Crossed 0-mark forwards
sensor->total_ticks += jump;
sensor->radians = (float)sensor->total_ticks * RAW_TO_RAD;
```

This converts the 12-bit "face angle" into a 32-bit `total_ticks` accumulator,
giving the robot an unbounded understanding of cumulative angular displacement.
The `RAW_TO_RAD` constant (`2π / 4096`) converts ticks directly to radians.

**Result:** The encoder now tracks infinite multi-turn rotation without sawtooth
artifacts. The sign of `total_ticks` naturally encodes rotation direction, so no
additional direction pin is required.

#### B. MUX Gatekeeper — I2C Routing

All four AS5600 encoders share a fixed I2C address (`0x36`). The TCA9548A
multiplexer isolates each encoder on its own channel. The `select_mux_channel()`
helper was finalized and encapsulated inside `read_regs()`, making channel
selection completely transparent to `main.cpp`:

```cpp
static void select_mux_channel(uint8_t mux_channel) {
    Wire.beginTransmission(MUX_ADDR);
    Wire.write(1 << mux_channel);  // Bitmask, not index
    Wire.endTransmission();
}
```

The critical detail is the bitmask — a raw index of `0` disables all channels
rather than selecting channel 0. This was the root cause of the "Ghost Readings"
(`65535`) encountered in the previous session. The abstraction prevents this class
of bug from ever surfacing in higher-level code.

#### C. Physical Quantity Derivation — Velocity

Velocity is derived by temporal differentiation of the radians field, synchronised
to the control interval:

```cpp
void as5600_get_velocity(as5600_t *sensor) {
    float prev_radians   = sensor->radians;
    as5600_update(sensor);
    float dt             = (float)CONTROL_INTERVAL_MS / 1000.0f;
    sensor->delta_rad    = sensor->radians - prev_radians;
    sensor->angular_velocity = sensor->delta_rad / dt;
}
```

`delta_rad` was added as a first-class field on `as5600_t`. Logging the per-step
displacement directly avoids downstream numerical differencing errors when replaying
CSV data offline — particularly important for EKF process model tuning where
floating-point accumulation errors in post-processing can distort Q matrix fits.

Because velocity is derived from the signed `jump` logic, negative values are
reported automatically for backward rotation with no additional direction logic.

#### D. Code Hardening — Compiler Warnings Resolved

Two warnings surfaced on the clean build and were addressed:

**`buffer[]` may be used uninitialized** — In `as5600_get_angle()`, the read buffer
was declared without initialisation. If `Wire.available()` returned false during
a failed I2C transfer, the angle assembly would operate on garbage values. Fixed:

```cpp
uint8_t buffer[2] = {0, 0};
```

A failed read now produces a zero-delta in `total_ticks` rather than a random
position jump — deterministic fault behaviour.

**`write_reg` defined but not used** — Retained intentionally. This function will
be used when the `AS5600_PREFERED_CONFIG` register write is implemented during
POST initialisation (hysteresis, power mode, slow filter settings).

**Final Memory Footprint After Full Integration**

| Resource | Used | Available | Utilisation |
|---|---|---|---|
| RAM | 4208 B | 32768 B | 12.8% |
| Flash | 26344 B | 262144 B | 10.0% |

Substantial headroom remains for motor control, PID instances, and the EKF state
estimator.

---

### Part 3: MATLAB Telemetry Suite — Full Separation

#### Architecture Decision: Four Independent Scripts

The combined 8-channel stream format from the previous session was identified as
an architectural problem for ongoing development:

- IMU calibration sessions require the robot stationary — encoder data is noise
- Encoder characterisation (slip tests, velocity sweeps) does not need IMU
- Combined analysis scripts make filter tuning harder to isolate per sensor
- Scaling to 4 encoders would make a combined format unmanageable

The suite was therefore divided into four independent, self-contained scripts:

| Script | Serial Columns | CSV Columns | Purpose |
|---|---|---|---|
| `imu_stream.m` | 6 | 7 | IMU live acquisition + export |
| `encoder_stream.m` | 2 | 3 | Encoder live acquisition + export |
| `imu_analysis.m` | — | 7 | Statistics, PSD, histograms, noise density |
| `encoder_analysis.m` | — | 3 | Kinematics, rollover health, velocity noise |

#### Graceful Stop — `try/finally` Pattern

A recurring failure mode with live stream scripts is data loss on Ctrl+C, where
execution never reaches the save block. The acquisition loop was wrapped in a
`try/finally` block ensuring the CSV save always executes regardless of exit cause
— figure close, Ctrl+C, or runtime error:

```matlab
finally
    clear device;
    if i > 0
        % save CSV with timestamp filename
    else
        fprintf('No data collected — nothing saved.\n');
    end
end
```

The `i > 0` guard prevents writing an empty file if the session is aborted before
any samples arrive.

#### Encoder Analysis — Diagnostics Beyond the IMU Script

Two encoder-specific diagnostics were added that have no IMU equivalent:

**Rollover Health Check** — Diffs the `EncRad` column and flags any step exceeding
`π` radians as a potential rollover artifact from `as5600_update()`. Zero detected
jumps confirms the boundary correction logic is operating correctly end-to-end.

**Dual Y-axis Velocity Plot** — Angular velocity is displayed simultaneously in
rad/s (left axis) and RPM (right axis) using `yyaxis`, removing the need for
mental unit conversion during test review sessions.

---

### Part 4: EKF Architecture — Mecanum Kinematic Implications

A design review was held on encoder data requirements ahead of EKF implementation,
with specific attention to how the mecanum drive geometry changes the architecture.

#### Key Architectural Conclusions

**Mecanum introduces a third independently controllable DOF.** Unlike differential
drive where lateral velocity is zero by constraint, mecanum requires `vy` as a
proper state:

```
State vector:  x = [px, py, θ, vx, vy, ω]
```

The dead reckoning update must apply the full 2D rotation matrix to transform
body-frame velocities into world-frame displacements:

```
px_new = px + (vx·cosθ − vy·sinθ) · dt
py_new = py + (vx·sinθ + vy·cosθ) · dt
θ_new  = θ + ω · dt
```

**Forward kinematics mixing matrix** (standard 45° roller layout):

```
vx = ( v_LF + v_RF + v_LR + v_RR) × (r/4)
vy = (-v_LF + v_RF + v_LR - v_RR) × (r/4)
ω  = (-v_LF + v_RF - v_LR + v_RR) × (r / 4(Lx+Ly))
```

**Lateral slip dominates encoder uncertainty.** Mecanum rollers slip laterally by
design — `σ_vy > σ_vx` is expected and must be characterised separately from
forward noise. A multiplicative noise model is more appropriate than additive for
the Q matrix:

```
σ_vy = k_y · |vy| + σ_0
```

Where `σ_0` is the quantisation floor from the static encoder test and `k_y` is
fit from a dedicated strafe calibration run.

**The IMU gyroscope is more valuable on mecanum than on differential drive.**
Wheel slip corrupts encoder-derived `ω` directly. Fusing gyro `ω` with encoder `ω`
in the EKF measurement update produces heading estimates that are robust to roller
slip — an advantage that does not exist on differential drive where encoder
odometry is inherently more reliable.

#### Calibration Runs Required Before EKF Tuning

| Test | Parameters Extracted |
|---|---|
| Pure forward, fixed speeds | `r`, `σ_vx`, scale error |
| Pure strafe, fixed speeds | Lateral slip coefficient, `σ_vy` |
| Pure rotation in place | `Lx + Ly`, `σ_ω` |
| Diagonal motion | Cross-coupling validation |
| Surface comparison | Slip model per surface type |

---

### Module Status Roadmap

| Module | Files | Status |
|---|---|---|
| POST / System Health | `lib/POST/post.cpp` | ✅ Stable |
| IMU Driver | `lib/IMU/imu.cpp` | ✅ Stable |
| AS5600 Encoder Driver | `lib/AS5600/as5600.cpp` | ✅ Complete — streaming live |
| MATLAB IMU Stream | `matlab/imu_stream.m` | ✅ Complete |
| MATLAB Encoder Stream | `matlab/encoder_stream.m` | ✅ Complete |
| MATLAB IMU Analysis | `matlab/imu_analysis.m` | ✅ Complete |
| MATLAB Encoder Analysis | `matlab/encoder_analysis.m` | ✅ Complete |
| Motor Control | `lib/MotorWheel/` | 📋 Planned |
| PID Controller | `lib/PID/` | 📋 Planned |
| Move Base / EKF | `lib/MoveBase/` | 📋 Planned |

---

### Files Added This Session

```
lib/AS5600/as5600.cpp                        — Encoder driver (complete)
lib/AS5600/as5600.h                          — Driver header with as5600_t struct
matlab/imu_stream.m                          — IMU-only live stream + CSV export
matlab/encoder_stream.m                      — Encoder-only live stream + CSV export
matlab/imu_analysis.m                        — IMU offline statistical analysis
matlab/encoder_analysis.m                    — Encoder offline kinematic analysis
```

### Next Steps
- [ ] **Add 3 remaining encoders** — replicate `enc_LF` pattern for RF, LR, RR;
      add mecanum forward kinematics block to `loop()` computing `vx`, `vy`, `ω`
- [ ] **IMU vibration test under motor load** — characterise noise floor increase
      relative to the 2026-04-01 stationary baseline
- [x] **Implement `MotorWheel` module** — extract motor control from `main.cpp`
      following the same driver pattern as IMU and AS5600
- [ ] **Implement `PID` module** — reentrant per-motor instances using the same
      struct pointer pattern as the sensor drivers

--------------------------------------------------------------------------------------------------------------------------------------------------------------------------------------------------------------

## 2026-04-04 — Motor Driver Module & Open-Loop System Identification

### Overview
Two major threads today: (1) implemented the `Motor` driver module following the
same component-based architecture established for the IMU and encoder drivers;
(2) designed and executed a structured open-loop characterisation session using a
new MATLAB test suite, extracting the key physical parameters of the motor-encoder
system needed to make an informed first attempt at PID tuning tomorrow.

---

### Part 1: Motor Driver Module

#### Architecture

The motor driver follows the same pattern as the IMU and encoder modules — a
struct holds all hardware state, and a set of functions operate on a pointer to
that struct. This makes the driver reentrant: declaring `motor_t motor_LF` and
`motor_t motor_RF` and calling the same functions on each is all that is needed
to support four independent motors without duplicating any logic.

```c
typedef struct {
    uint8_t motor_pwm_pin;
    uint8_t motor_pin1;
    uint8_t motor_pin2;
    uint8_t motor_enable_pin;
    float   current_power;   // -100.0 to +100.0
    bool    is_inverted;     // software direction flip if wired backwards
} motor_t;
```

#### Key Implementation Details

**Power representation** uses a -100.0 to +100.0 percentage scale rather than
raw PWM (0–255). This decouples the control logic from the hardware, making the
PID output human-readable and portable if the MCU or driver chip ever changes.
The conversion to PWM happens only at the lowest level inside `motor_set_speed()`:

```cpp
uint8_t pwm = (uint8_t)map(fabs(power), 0.0f, 100.0f, 0, 255);
```

**Direction control** is handled by the TB6612FNG H-bridge logic. IN1/IN2 set
the direction, PWM sets the magnitude, and the STANDBY pin enables or disables
the entire driver chip. The four operating states are:

| IN1 | IN2 | PWM | Behaviour |
|-----|-----|-----|---|
| HIGH | LOW | >0 | Forward |
| LOW | HIGH | >0 | Reverse |
| LOW | LOW | any | Coast (free spin) |
| HIGH | HIGH | 255 | Brake (short circuit) |

**Braking** applies full PWM with both IN pins HIGH, creating a short-circuit
across the motor terminals that generates maximum resistive braking torque.
This is used for emergency stops, not normal deceleration.

**`is_inverted` flag** is reserved for the case where a motor is physically wired
backwards on the robot chassis. Setting this flag in software flips the direction
without rewiring — important when all four mecanum wheels are mounted and some
face opposite directions.

#### Non-Blocking Serial Command Interface

A key change to `main.cpp` was replacing `Serial.parseFloat()` with a
character-by-character accumulation buffer:

```cpp
String serial_buffer = "";

while (Serial.available()) {
    char c = Serial.read();
    if (c == '\n') {
        if (serial_buffer.length() > 0) {
            float commanded_power = serial_buffer.toFloat();
            motor_set_speed(&motor_LF, commanded_power);
        }
        serial_buffer = "";
    } else {
        serial_buffer += c;
    }
}
```

`parseFloat()` blocks the entire loop for up to the Serial timeout period while
waiting for more digits. During that blocking window, the encoder cannot be read
and no data is streamed. The buffer approach reads one character at a time, acts
only when a newline arrives, and never stalls the control loop. The `length() > 0`
guard prevents a bare newline from triggering a `toFloat()` call that returns 0.0
and silently stops the motor.

---

### Part 2: Open-Loop System Identification — What We Did and Why

Before implementing a PID controller, we need to understand how the physical
system behaves. This section explains the MATLAB test suite in plain terms and
documents what each result means.

#### The Core Question: What Are We Trying to Learn?

A PID controller works by computing an error (the difference between where the
wheel is and where we want it to be) and converting that error into a motor power
command. But to choose the right PID gains, we first need to know three things:

1. **What is the minimum power to make the wheel move at all?** — Deadband
2. **How fast does the wheel spin at each power level?** — Plant Gain K
3. **How quickly does the wheel reach its target speed?** — Time Constant τ

The MATLAB script answers all three automatically by commanding the motor and
reading the encoder response.

#### How the MATLAB-Arduino Communication Works

MATLAB acts as the test controller. Arduino acts as the executor and reporter.
They talk over the USB serial cable:

```
MATLAB sends:   "40.00\n"
Arduino reads:  serial_buffer = "40.00" → motor_set_speed(40.0) → wheel spins

Arduino sends:  "12345,40.00,1.234567,8.910000\n"
                [Time_ms, Power_pct, Angle_rad, Vel_rads]
MATLAB reads:   stores the 4 numbers in a growing data matrix
```

MATLAB stores every line in a buffer, then analyses the numbers after each
segment ends. The motor never needs to be reprogrammed between tests — MATLAB
drives everything dynamically over serial.

#### Test 1: Deadband Identification — "What is the Minimum Effective Power?"

**The concept:** A motor with a gearbox does not move the moment you apply any
power. There is a threshold below which friction in the gearbox exceeds the
motor's torque output. Below this threshold, the motor hums but the wheel stays
still. This threshold is the *deadband*.

**What the test does:** MATLAB commands power levels from 5% to 60% in steps of
5%, holding each for 2.5 seconds. Before each step it stops the motor and flushes
the serial buffer to prevent stale readings contaminating the new segment. After
each segment it computes the mean absolute velocity. When this mean exceeds a
noise threshold of 0.05 rad/s, the wheel has started moving — that power level
is the deadband.

**Why this matters for PID:** If a PID controller outputs 15% power and the
deadband is 30%, the motor does nothing. The integrator keeps accumulating error,
the output keeps climbing, and when the wheel finally breaks free it lurches
violently. Knowing the deadband lets us clamp the PID output to never command
below it when motion is intended.

**Result: Deadband = 30%**

The wheel produced no meaningful motion below 30%. At 30% and above, velocity
rose cleanly and monotonically. This is a relatively high deadband, typical of
brushed DC motors with plastic gearboxes.

#### Test 2: PWM-to-Velocity Map — "How Fast Does the Wheel Spin per Unit of Power?"

**The concept:** Once above the deadband, there is a relationship between how
much power we command and how fast the wheel spins at steady state. If this
relationship is approximately linear, we can describe it with a single number
called the *plant gain K*.

**What the test does:** MATLAB commands fixed power levels from ±30% to ±100%,
holding each for 3 seconds. For each level, it discards the first 1500ms (the
acceleration transient) and computes the mean velocity from the remaining
steady-state tail. It then fits a straight line through all the (power, velocity)
pairs. The slope of that line is K.

**The linear model:**

```
velocity (rad/s) = K × power (%)
K = 0.2291 (rad/s) per % power
```

This means for every 1% of power above the deadband, the wheel gains
approximately 0.23 rad/s. At 100% power the wheel reaches ~23 rad/s
(approximately 220 RPM).

**Forward vs Reverse symmetry:**

| Direction | Velocity at 100% |
|---|---|
| Forward | 23.02 rad/s |
| Reverse | 23.95 rad/s |

Only 4% asymmetry — excellent for a brushed motor. Separate PID gains per
direction are not needed.

**Why K matters for PID:** K tells us how sensitive the system is to our
commands. The mathematical starting point for Kp is simply `1/K` — if the system
is less sensitive (small K) we need a larger proportional gain to make up for it.

**Result: K = 0.2291 → suggests Kp ~ 4.37**

#### Test 3: Step Response — "How Quickly Does the Wheel Respond?"

**The concept:** When we suddenly apply a fixed power command, the wheel does not
instantly reach its target speed. It accelerates over a period of time, limited
by the motor's inertia and back-EMF. The characteristic time of this rise is the
*time constant τ*.

**What the test does:** MATLAB commands a sudden jump from 0% to a fixed power
level (40%, 60%, 100%) and records the encoder velocity every 10ms for 4 seconds.

**What τ means:** τ is defined as the time for the velocity to reach 63.2% of
its final steady-state value. This comes from the mathematics of first-order
systems — a motor-gearbox behaves approximately like:

```
velocity(t) = v_steady × (1 − e^(−t/τ))
At t = τ:  velocity = v_steady × 0.632
```

In the MATLAB code this is found by scanning the velocity array for the first
sample that crosses the 63.2% mark:

```matlab
v_ss    = mean(vel(end-10:end));         % steady-state from last 10 samples
tau_idx = find(vel >= 0.632 * v_ss, 1); % first crossing of 63.2%
tau     = t_rel(tau_idx);               % elapsed time at that index
```

**Why τ matters for PID:**
- A small τ means the motor responds quickly
- Ki eliminates steady-state error and should operate on the timescale of τ: `Ki = Kp / τ`
- Kd adds damping proportional to the rate of change: `Kd = Kp × τ × 0.1`

**Result: τ = 0.10 s**

The wheel reaches 63.2% of its steady-state speed in 100ms. With a 10ms control
interval, the PID loop completes 10 cycles within one time constant — more than
sufficient resolution for stable control.

#### Computed PID Starting Points

| Parameter | Formula | Value |
|---|---|---|
| Kp | 1 / K | 4.37 |
| Ki | Kp / τ | 43.66 |
| Kd | Kp × τ × 0.1 | 0.044 |

These are mathematically derived starting points, not final values. For
tomorrow's tuning session, we start conservatively:

```
Kp = 2.0   — half the computed value to avoid overshoot on first run
Ki = 0.0   — add only after Kp is stable
Kd = 0.0   — add last if oscillation appears
```

**Tuning sequence for tomorrow:**
1. Increase Kp until the wheel tracks a setpoint with acceptable overshoot
2. Add Ki to eliminate the steady-state error that persists when Kp alone is used
3. Add Kd only if the response oscillates or overshoots significantly

#### The Feedforward Insight

Because the deadband is large (30%), a purely reactive PID controller will
struggle at low speeds — the integrator winds up trying to overcome the deadband,
causing a lurch when the motor finally breaks free. A better approach adds a
*feedforward* term that maps the desired velocity directly to a base power level:

```
output = deadband_pct + (desired_velocity / K)
PID corrects only the residual error on top of this baseline
```

This will be implemented as part of the PID module.

---

### Troubleshooting Log — Serial Communication Bugs

Three separate bugs were encountered and resolved during the MATLAB integration:

| Bug | Symptom | Root Cause | Fix |
|-----|---|---|-----|
| `parseFloat()` blocking | Motor unresponsive during sweep | parseFloat blocks loop for full timeout | Non-blocking char buffer |
| Double newline | Motor stops instantly after command | `writeline` + `\n` in sprintf = two newlines | Remove `\n` from sprintf |
| Second `flush()` eating data | All velocities read as 0.0 | flush after command discarded real measurements | Remove post-command flush |

These bugs reinforced a key principle: **serial timing bugs are invisible.**
The motor was visibly spinning during most of these failures, which made them
harder to identify. The fix was to treat the serial protocol as a strict contract:
one side sends, the other receives, and nothing flushes the pipe while data is
expected.

---

### Module Status Roadmap

| Module | Files | Status |
|---|---|---|
| POST / System Health | `lib/POST/post.cpp` | ✅ Stable |
| IMU Driver | `lib/IMU/imu.cpp` | ✅ Stable |
| AS5600 Encoder Driver | `lib/AS5600/as5600.cpp` | ✅ Stable |
| Motor Driver | `lib/Motor/motor.cpp` | ✅ Complete |
| MATLAB Open-Loop Suite | `matlab/motor_openloop_test.m` | ✅ Complete |
| PID Controller | `lib/PID/` | 🔄 Next — parameters ready |
| Move Base / EKF | `lib/MoveBase/` | 📋 Planned |

---

### Files Added This Session

```
lib/Motor/motor.cpp                           — Motor driver implementation
lib/Motor/motor.h                             — Motor struct and function prototypes
src/main.cpp                                  — Updated with non-blocking serial parser
matlab/motor_openloop_test.m                  — Full open-loop characterisation suite
matlab/CSVs/openloop_sweep_2026-04-04.csv     — Sweep results (power vs velocity)
matlab/CSVs/openloop_step40_2026-04-04.csv   — Step response at 40%
matlab/CSVs/openloop_step60_2026-04-04.csv   — Step response at 60%
matlab/CSVs/openloop_step100_2026-04-04.csv  — Step response at 100%
```

### System Identification Results Summary

| Parameter | Value | Unit |
|---|---|---|
| Deadband | 30 | % power |
| Plant gain K | 0.2291 | (rad/s)/% |
| Max velocity | 23.95 | rad/s |
| Time constant τ | 0.10 | s |
| Fwd/Rev asymmetry | 4 | % |
| Suggested Kp | 4.37 | — |
| Suggested Ki | 43.66 | — |
| Suggested Kd | 0.044 | — |

### Next Steps

- [ ] **Implement PID module** — reentrant `pid_t` struct with Kp, Ki, Kd,
      integral accumulator, derivative filter, output clamping, and anti-windup
- [ ] **Integrate feedforward** — map desired velocity to base power using K and
      deadband offset; PID corrects residual error only
- [ ] **Closed-loop step test** — command a velocity setpoint, record actual
      velocity, tune gains until response is satisfactory
- [ ] **Extend to 4 motors** — replicate motor_t for RF, LR, RR; add mecanum
      forward kinematics to compute body vx, vy, ω

--------------------------------------------------------------------------------------------------------------------------------------------------------------------------------------------------------------

## 2026-04-05 — Plant Modelling, PID Auto-Tuning & Simulink Validation

### Overview
Before writing a single line of PID code, we took a step back and modelled the
motor-encoder system mathematically, then used MATLAB's built-in `pidtune()`
function to compute optimal gains automatically from that model. The gains were
then validated inside a Simulink simulation to confirm the closed-loop behaviour
before any hardware was touched. This session bridges the open-loop measurements
from yesterday to the PID firmware implementation tomorrow.

#### Reference Material
Brian Douglas' *Control System Lectures* playlist on YouTube was used as the
primary reference for understanding PID implementation theory, discretisation,
anti-windup, and filtered derivative concepts:
https://youtube.com/playlist?list=PLn8PRpmsu08pQBgjxYFXSsODEF3Jqmm-y

---

### Part 1: What Is a Transfer Function and Why Do We Need One?

#### The Problem With Guessing PID Gains

A PID controller has three knobs: Kp, Ki, and Kd. If you turn them randomly, the
wheel might overshoot wildly, oscillate forever, or respond too slowly to be
useful. To choose them intelligently, you need a mathematical description of how
the motor physically responds to a command. This description is called the
**transfer function**.

#### The Transfer Function G(s) — In Plain English

Think of the transfer function as the motor's "personality profile." It answers
the question: *if I send this power command, what velocity will I get, and how
quickly?*

For our motor, yesterday's open-loop tests revealed that it behaves like a
**first-order system** — the simplest possible dynamic system. This means:

- It has one source of "sluggishness" (mechanical inertia)
- Its velocity rises smoothly toward a final value, never oscillating on its own
- It is fully described by just two numbers: K and τ

The transfer function is written as:

```
G(s) = K / (τs + 1)
G(s) = 0.2291 / (0.1s + 1)
```

Where:
- **K = 0.2291** is the plant gain — how many rad/s you get per % of power at
  steady state
- **τ = 0.1s** is the time constant — how quickly the motor reaches that speed
- **s** is a mathematical operator (the Laplace variable) that represents
  frequency; it allows us to analyse the system's behaviour across all speeds
  of input change simultaneously, not just for one specific input

In practical terms, this equation says: "apply 40% power, and after about 0.3
seconds (3τ) the wheel will be spinning steadily at 40 × 0.2291 = 9.16 rad/s."
Yesterday's measurement confirmed exactly this — the steady-state velocity at 40%
was 8.95 rad/s, which matches the model to within 2%.

---

### Part 2: The Bode Plot — Reading the Motor's Frequency Response

The Bode plot is a standard engineering tool that shows how well the motor tracks
commands at different speeds of change. There are two panels:

**Magnitude plot (top)** — shows how much of the commanded velocity actually
appears at the output, expressed in decibels (dB). 0 dB means perfect tracking;
negative dB means the output is weaker than the command.

**Phase plot (bottom)** — shows how much the output lags behind the command in
time, expressed in degrees. 0° means no lag; -90° means the output is a quarter
cycle behind the input.

#### What Our Bode Plot Shows

```
Low frequencies (slow commands, < 1 rad/s):
  Magnitude ≈ -13 dB = our gain K expressed logarithmically
  Phase ≈ 0° — the wheel tracks slow commands faithfully with no lag

Corner frequency at 10 rad/s (= 1/τ = 1/0.1):
  This is where the motor starts struggling to keep up
  Magnitude begins rolling off at -20 dB per decade
  Phase starts dropping toward -45°

High frequencies (fast commands, > 100 rad/s):
  Magnitude continues dropping — the motor physically cannot follow
  Phase approaches -90° — the output lags badly behind the command
```

The key insight is that a first-order system never loses more than 90° of phase,
no matter how fast the input changes. This makes it **inherently stable** — you
cannot make it oscillate just by increasing the gain. This is what makes our
motor-gearbox system relatively straightforward to control.

---

### Part 3: How pidtune() Works — Automatic Gain Calculation

`pidtune()` is MATLAB's automatic PID gain calculator. You hand it the transfer
function and the type of controller you want, and it returns the optimal gains.

#### What "Optimal" Means Here

`pidtune()` targets a **phase margin of 60°** by default. Phase margin is a
measure of how far the system is from instability — 0° means it is right on the
edge of oscillating, 60° means it has a comfortable safety buffer. This is an
industry standard for robust control: the system will remain stable even if the
real motor behaves somewhat differently from the model.

#### The Four Controllers Compared

```matlab
C_p    = pidtune(G, 'P');    % proportional only
C_pi   = pidtune(G, 'PI');   % proportional + integral
C_pid  = pidtune(G, 'PID');  % proportional + integral + derivative
C_fast = pidtune(G, 'PID', opts);  % PID with faster target bandwidth
```

Results:

| Controller | Kp | Ki | Kd |
|---|---|---|---|
| P | 8.9170 | — | — |
| PI | 4.5508 | 136.57 | — |
| PID | 6.2497 | 113.28 | 0.0 |
| PID fast | 7.1885 | 132.09 | 0.0 |

#### Why Kd = 0 Is the Correct Answer

`pidtune()` returned `Kd = 0` for both PID variants. This surprises people who
expect PID to always use all three terms, but it is mathematically correct here.

The derivative term amplifies high-frequency changes in the error signal. The
faster the error changes, the larger the derivative output. The problem is that
encoder velocity readings contain quantisation noise — small random jumps that
look like very fast changes. A non-zero Kd would amplify this noise directly into
the motor command, causing jitter and heat.

For our motor with τ = 0.1s, the system is already fast enough that derivative
action provides no meaningful benefit. `pidtune()` correctly identifies this and
sets Kd = 0, making this effectively a PI controller. **Trust the maths.**

---

### Part 4: Simulated Performance — Comparing Controllers

To evaluate each controller before touching hardware, we simulated a step command
— the wheel is asked to jump from 0 to 1 rad/s instantly — and observed how each
controller responds.

#### What Each Metric Means

**Settling time** — how long until the wheel stays within 2% of the target and
stays there. A shorter settling time means faster response.

**Overshoot** — how much the wheel exceeds the target before correcting. Expressed
as a percentage of the target. Some overshoot is normal; too much means the
controller is aggressive and will cause mechanical stress.

**Steady-state error** — the permanent gap between the target and the actual speed
after the transient dies out. For a robot wheel, this must be zero — if you command
5 rad/s and the wheel settles at 4.6 rad/s, your robot will drift.

#### Results

| Controller | Settle | Overshoot | SS Error | Verdict |
|---|---|---|---|---|
| P | 2.000 s | 0.0% | 32.87% | ❌ Unusable — permanent 33% error |
| PI | 0.296 s | 13.8% | 0.00% | ⚠️ Fast but bouncy |
| PID | 0.317 s | 6.1% | 0.00% | ✅ Best balance |
| PID fast | 0.292 s | 6.5% | 0.00% | ✅ Slightly faster, slightly bouncier |

**Why P alone fails:** A proportional controller outputs power proportional to
error. As the wheel approaches the target, the error shrinks, the output shrinks,
and the two reach equilibrium before zero error is achieved. The 32.87% permanent
offset is not a bug — it is a fundamental mathematical property of P control on
this type of plant. The integral term exists specifically to drive this error to
zero by accumulating error over time and continuously pushing until it disappears.

**Why PID was chosen over PID fast:** The standard PID settles in 317ms with 6.1%
overshoot. The fast variant settles in 292ms (25ms faster) but with 6.5% overshoot.
For a wheel velocity controller on a robot, that extra 25ms is not worth the
additional overshoot which would cause the robot to jerk slightly at every speed
change.

---

### Part 5: Simulink Validation — The Final Check Before Hardware

Rather than rebuilding the Simulink model from scratch on every run, a permanent
`motor_pid_simulation_final.slx` model was created and saved. The MATLAB script
loads this model, injects the gains from `pid_gains.mat`, runs the simulation,
and reports the results.

#### What the Simulink Model Contains

```
[Step Setpoint] → [Sum] → [PID Controller] → [Dead Zone] → [Plant G(s)] → [Scope]
                    ↑                                              |
                    └──────────────── feedback ───────────────────┘
```

- **Step Setpoint** — commands the wheel to jump to 10 rad/s at t=0
- **Sum** — computes the error (setpoint minus actual velocity)
- **PID Controller** — applies Kp, Ki, Kd to the error
- **Dead Zone** — models the 30% deadband; any command below ±30% is treated as
  zero, just as the real hardware behaves
- **Plant G(s)** — the transfer function representing the motor-encoder system
- **Feedback loop** — feeds the plant output back to the sum block to close the loop

#### Simulation Results

```
Rise time:     0.126 s   — wheel reaches 63% of 10 rad/s in 126ms
Settling time: 0.329 s   — within 2% of 10 rad/s in 329ms
Overshoot:     3.2%      — wheel briefly hits 10.32 rad/s before settling
Steady-state:  10.0000   — perfect, zero permanent error
```

The overshoot in Simulink (3.2%) is lower than in the lsim comparison (6.1%)
because the Simulink model includes the Dead Zone block. In the early moments of
a step response the PID output is very large, but the Dead Zone clips the
lower-end commands during the settling phase, which naturally reduces overshoot.
The Simulink result is the more realistic prediction of what the real hardware
will do.

329ms settling time with a 10ms control loop means the PID converges in
approximately 33 control cycles — fast enough for smooth tracking, stable enough
not to fight itself.

---

### Part 6: Anti-Windup — A Critical Implementation Requirement

Ki = 113.28 is a large value. This creates a specific risk called **integrator
windup** that must be addressed in the firmware before the PID is used on hardware.

**What windup means:** The integral term accumulates error over time. If the wheel
is blocked or stalled, the PID cannot reach the setpoint, so error keeps
accumulating. With Ki = 113, just one second of stall accumulates 113 units of
integral output. When the wheel finally frees, this accumulated value causes it to
lurch violently far past the setpoint.

**The fix — anti-windup clamping:** The integral accumulator must be hard-limited
to the output range (±100% power). If the output is already saturated, the
integrator stops accumulating. This is the first feature to implement in the
PID library tomorrow, before any other functionality.

```cpp
// Anti-windup: clamp integral accumulator to output limits
integral += Ki * error * dt;
integral  = constrain(integral, output_min, output_max);
```

---

### Final Arduino PID Starting Values

These are the values exported to `pid_gains.mat` and ready to copy directly into
the PID firmware:

```cpp
float Kp       = 6.2497;
float Ki       = 113.2799;
float Kd       = 0.0000;   // Derivative not needed — PI controller
float deadband = 30.0;     // % power — from Test 1
float dt       = 0.010;    // 10ms control interval
```

---

### Module Status Roadmap

| Module | Files | Status |
|---|---|---|
| POST / System Health | `lib/POST/post.cpp` | ✅ Stable |
| IMU Driver | `lib/IMU/imu.cpp` | ✅ Stable |
| AS5600 Encoder Driver | `lib/AS5600/as5600.cpp` | ✅ Stable |
| Motor Driver | `lib/Motor/motor.cpp` | ✅ Stable |
| MATLAB Open-Loop Suite | `matlab/motor_openloop_test.m` | ✅ Complete |
| MATLAB Model & Tune | `matlab/motor_model_and_tune.m` | ✅ Complete |
| Simulink Model | `matlab/motor_pid_simulation_final.slx` | ✅ Complete |
| PID Controller | `lib/PID/` | 🔄 Next — gains ready |
| Move Base / EKF | `lib/MoveBase/` | 📋 Planned |

---

### Files Added This Session

```
matlab/motor_model_and_tune.m                 — Plant identification, pidtune(), simulation
matlab/motor_pid_simulation_final.slx         — Permanent Simulink closed-loop model
matlab/CSVs/pid_gains.mat                     — Exported Kp, Ki, Kd, K, τ, deadband
```

### Key Results Summary

| Parameter | Value | Unit |
|---|---|---|
| Transfer function | 0.2291 / (0.1s + 1) | — |
| Chosen controller | PI (PID with Kd=0) | — |
| Kp | 6.2497 | — |
| Ki | 113.2799 | — |
| Kd | 0.0000 | — |
| Simulated rise time | 0.126 | s |
| Simulated settling time | 0.329 | s |
| Simulated overshoot | 3.2 | % |
| Steady-state error | 0.0000 | rad/s |

### Next Steps

- [ ] **Implement PID library** — `pid_t` struct with Kp, Ki, Kd, integral
      accumulator, anti-windup clamping, output saturation, and dt
- [ ] **Anti-windup first** — with Ki = 113, integrator windup is not optional;
      implement and test clamping before any closed-loop hardware run
- [ ] **Closed-loop step test** — command a velocity setpoint over serial,
      stream actual velocity back to MATLAB, compare against Simulink prediction
- [ ] **Feedforward integration** — combine PID with deadband-offset feedforward
      for improved low-speed tracking
- [ ] **Extend to 4 motors** — replicate motor_t and pid_t for RF, LR, RR

--------------------------------------------------------------------------------------------------------------------------------------------------------------------------------------------------------------

## 2026-04-13 — PID Library Implementation & First Closed-Loop Hardware Tests

### Overview
Two major threads today: (1) implemented the PID controller library following the
same component-based pattern as the IMU, encoder, and motor drivers; (2) ran the
first closed-loop velocity control tests on hardware, discovering and resolving
three critical bugs that prevented the controller from working. By end of session
the wheel was tracking velocity setpoints over serial with MATLAB live monitoring.

---

### Part 1: PID Controller Library

#### Architecture

The PID driver follows the same reentrant struct pattern as every other module.
All state and configuration lives in `pid_ctrl_t`, and functions operate on a
pointer to it. Declaring `pid_ctrl_t pid_LF` and `pid_ctrl_t pid_RF` with the
same functions gives four independent controllers without duplicating logic.

```c
typedef struct {
    float kp, ki, kd;             // Gains
    float kff;                    // Feedforward gain
    float deadband;               // % power offset
    float output_min, output_max; // Output limits (-100 to 100)
    float dt;                     // Control interval in seconds
    float setpoint;               // Target velocity (rad/s)
    float last_error;             // For derivative term
    float integral_sum;           // For integral term
} pid_ctrl_t;
```

#### Anti-Windup — Clamping Method

The integral accumulator is only updated when the output is within limits. If the
output saturates, the integrator freezes:

```c
if (output > pid->output_max)      output = pid->output_max;
else if (output < pid->output_min) output = pid->output_min;
else                               pid->integral_sum += error * pid->dt;
```

This prevents the integrator winding up during stall or saturation — a critical
requirement given Ki=113 in the initial gains.

#### `pid_init()` calls `pid_reset()`

Rather than duplicating zeroing logic, `pid_init()` calls `pid_reset()` at the
end to zero all state fields. This ensures the struct is always clean on
initialisation regardless of memory contents:

```c
void pid_init(...) {
    pid->kp = kp; pid->ki = ki; // assign all config...
    pid_reset(pid);              // zero all state
}
```

---

### Part 2: Critical Bugs Found and Fixed

#### Bug 1 — Missing `dt` in Integral Accumulation

The most damaging bug. The integral was implemented as:

```c
pid->integral_sum += error;          // WRONG
i_term = pid->ki * pid->integral_sum;
```

With Ki=113.28 and a 10 rad/s setpoint, after the first cycle:
- `integral_sum = 10` (first error value)
- `i_term = 113.28 × 10 = 1132%` — 11x over the output limit

The motor clamped to 100% instantly and stayed there. The fix:

```c
pid->integral_sum += error * pid->dt;  // CORRECT
```

Now with dt=0.02: `i_term = 113.28 × 0.1 = 11.3%` per second — completely sane.

#### Bug 2 — `motor_set_speed()` Using Wrong Variable

After applying the deadband offset to create `final_power`, all subsequent
direction checks and PWM calculation still used the original `power` variable:

```cpp
float final_power = power + MOTOR_DEADBAND;  // computed correctly
if (power > 0.1) { ... }                     // but direction used 'power' ❌
uint8_t pwm = map(fabs(power), ...);         // PWM also used 'power' ❌
```

Direction was being set from the pre-deadband value while PWM was driven from
the post-deadband value — causing erratic behaviour near the deadband boundary.
All checks changed to use `final_power`.

#### Bug 3 — Motor Running Before Any Command

Arduino enters `loop()` immediately after calibration. With setpoint=0 and
encoder noise producing non-zero `current_velocity`, the error was non-zero and
the motor started spinning before MATLAB connected. Fixed with a gate flag:

```cpp
bool setpoint_received = false;

// Gate: motor only runs after first command arrives
if (setpoint_received) {
    float target_power = pid_compute(&pid_LF, current_velocity);
    motor_set_speed(&motor_LF, target_power);
} else {
    motor_set_speed(&motor_LF, 0.0f);
}
```

---

### Part 3: Serial Protocol Upgrade

The serial interface was upgraded from raw float commands to a structured
prefix protocol, allowing MATLAB to change gains live without reflashing:

```
S:<float>  — set velocity setpoint (rad/s), opens gate
P:<float>  — update Kp, resets integral
I:<float>  — update Ki, resets integral
D:<float>  — update Kd, resets integral
F:<float>  — update Kff, resets integral
R:         — full reset, stop motor, close gate
```

Telemetry expanded from 4 to 7 columns:
```
Time_ms, Setpoint, Velocity, Power, Kp, Ki, Kd
```

Active gains are echoed every cycle so MATLAB can verify commands were received
before logging a segment — this eliminates contamination from transition windows
where old gains are still active.

---

### Part 4: MATLAB Live Monitor

`matlab_live_pid_monitor.m` was rebuilt with a non-blocking UI. The previous
version used `input()` for setpoint entry which blocked the serial loop and
caused Arduino to disconnect every time the user typed. The fix uses a figure
text box and Send button — the serial loop never pauses.

Additional features added:
- **Stop button** — sends `R:` then `S:0.00`
- **Sequence runner** — enter `7,10,13,15` and a hold time; steps through
  setpoints automatically with `pause()` between them
- **Dark mode palette** — blue velocity, amber setpoint, green power, dark axes
- **7-column storage** — buffer now captures Kp, Ki, Kd alongside telemetry
- **CSV save on any exit** — figure close, Ctrl+C, or runtime error

---

### Module Status Roadmap

| Module | Files | Status |
|---|---|---|
| POST / System Health | `lib/POST/post.cpp` | ✅ Stable |
| IMU Driver | `lib/IMU/imu.cpp` | ✅ Stable |
| AS5600 Encoder Driver | `lib/AS5600/as5600.cpp` | ✅ Stable |
| Motor Driver | `lib/Motor/motor.cpp` | ✅ Stable |
| PID Controller | `lib/PID/pid_controller.c` | ✅ Complete |
| MATLAB Live Monitor | `matlab/matlab_live_pid_monitor.m` | ✅ Complete |
| 4-Wheel Integration | `src/main.cpp` | 📋 Next |

### Next Steps

- [ ] **Run automated gain sweep** — MATLAB commands gains over serial,
      logs response per combination, ranks by composite score
- [ ] **Add feedforward** — baseline power from setpoint directly to
      reduce integrator load and improve low-speed tracking
- [ ] **Multi-setpoint validation** — confirm gains hold across 7–15 rad/s
- [ ] **Extend to 4 motors** — replicate motor_t and pid_t for RF, LR, RR

--------------------------------------------------------------------------------------------------------------------------------------------------------------------------------------------------------------

## 2026-04-24 — Automated PID Sweep, Feedforward Integration & Final Tuning

### Overview
Three major threads today: (1) built and ran an automated MATLAB gain sweep to
identify optimal PID values empirically from real hardware data; (2) implemented
and debugged a feedforward term that reduced settling time by 14x; (3) ran a full
multi-setpoint validation confirming the controller works cleanly across the entire
7–15 rad/s operating range. Single-wheel closed-loop velocity control is complete.

---

### Part 1: Why the MATLAB Model Gains Failed on Hardware

The gains computed by `pidtune()` on 2026-04-05 were `Kp=6.25, Ki=113.28`.
Seven hardware sessions with these gains all produced violent oscillation between
±23 rad/s — the wheel never settled. Two root causes were identified:

**Root cause 1 — Missing `dt` in integral accumulation (described in previous
entry).** With `integral_sum += error` instead of `integral_sum += error * dt`,
Ki=113 accumulated error 50x faster than the model assumed.

**Root cause 2 — Deadband compensation changes the effective plant gain.** The
linear model `G(s) = 0.2291 / (0.1s + 1)` was identified from open-loop data
where `motor_set_speed()` received raw power percentages. In closed-loop,
`motor_set_speed()` adds 30% to every non-zero output. This shifts the effective
plant gain significantly — a PID output of 10% becomes 40% at the motor, making
the real loop gain ~4x higher than the model assumed. Ki=113 on this modified
plant caused the oscillation the model said would never happen.

**The lesson:** Model-derived gains are starting points. Any unmodelled nonlinearity
in the real plant — deadband, friction, saturation — changes the effective loop
gain and requires empirical correction.

---

### Part 2: Automated Gain Sweep — Finding the Real Working Gains

Rather than manually reflashing for each gain combination, MATLAB was extended to
send gains over serial using the `P:/I:/D:` command protocol. The sweep script
tests every combination in a grid, logs the response, computes metrics, ranks
results, and saves everything to CSV automatically.

#### Sweep 1 — Ki range 0.5 to 5.0 (no feedforward)

Initial hypothesis: Ki must be much lower than 113. First sweep used
`Kp=[4,6,8,10]` and `Ki=[0.5,1,2,5]`.

**Result: All combinations showed zero overshoot and zero oscillation — but also
zero settling.** Every combination was still ramping at the end of the 5-second
window. The integrator was so weak it could not accumulate enough output to
overcome the deadband and reach steady state. Ki=5 was the lowest value that
showed any sign of settling.

**Insight:** With the correct `error * dt` formulation, one second of 5 rad/s
error accumulates `5 × 0.02 × 50 = 5` in the integrator. With Ki=5 that is only
25% power after one second — still not enough to hold 10 rad/s which needs ~74%.
The integrator needs more time or higher Ki.

#### Sweep 2 — Ki range 5 to 30 (no feedforward)

Second sweep: `Kp=[6,8,10,12]`, `Ki=[5,10,20,30]`, `SETTLE_WINDOW=10s`.

**Winner: Kp=10, Ki=30** — 0.84s settling, 8.9% overshoot, 0.1% SS error.

This was a genuine step change. Ki=30 accumulated enough integral action within
the window to drive the output to steady state without oscillating. The settling
time bar chart showed Kp=10, Ki=30 at 0.84s while every other combination was
still above 3s.

#### Multi-setpoint validation without feedforward

Tested Kp=10, Ki=30 at 5, 10, 15, 20 rad/s:
- 5 rad/s: settled at 3.14s, 19.6% overshoot — deadband dominates at low speed
- 10 rad/s: settled at 0.56s, 10.5% overshoot — good
- 15 rad/s: settled at 5.80s — approaching saturation
- 20 rad/s: never settled — physically beyond motor capability at 7.4V

Operating range without feedforward: **8–15 rad/s**.

---

### Part 3: Feedforward — What It Is and Why It Helps

#### The Problem with Pure PI Control

A PI controller starts from zero output and climbs toward the required level
purely through error accumulation. At 10 rad/s the motor needs ~74% power. The
integral must build from 0% to 74% before the wheel reaches target speed. During
this ramp the wheel is below setpoint, the error is large, and the integral keeps
growing — causing overshoot when it finally arrives.

#### The Feedforward Solution

Feedforward computes the expected power needed to reach the setpoint directly
from the plant inverse, bypassing the integrator entirely for the steady-state
component:

```
ff_term = sign(setpoint) × Kff × |setpoint|
Kff = 1/K = 1/0.2291 = 4.366
```

At setpoint = 10 rad/s: `ff_term = 4.366 × 10 = 43.66%`

`motor_set_speed()` then adds the 30% deadband offset: `43.66 + 30 = 73.66%` —
exactly the power the motor needs. The integrator only corrects the small residual
error caused by friction, load variations, and encoder noise.

The total PID+FF output:

```
output = ff_term + Kp×error + Ki×integral_sum + Kd×d_error/dt
```

#### The Double Deadband Bug

First implementation of feedforward included the deadband inside the ff_term:

```c
ff_term = pid->deadband + pid->kff * pid->setpoint;  // WRONG
```

`motor_set_speed()` then added another 30%:
```
total = (30 + 43.66) + 30 = 103.66% → clamped to 100%
```

The motor was commanded to 100% from cycle 1 of every test — causing 22–44%
overshoot across every gain combination regardless of Kp or Ki. The fix removes
deadband from `pid_compute()` entirely:

```c
// CORRECT — motor_set_speed() handles deadband
ff_term = sign * pid->kff * fabsf(pid->setpoint);
```

This also fixes reverse direction — at -10 rad/s: `ff_term = -43.66%`, then
`motor_set_speed()` subtracts 30%: `final = -73.66%`. Correct.

#### Sweep 3 — With Corrected Feedforward

Grid: `Kp=[4,6,8,10]`, `Ki=[2,5,10,15]`, `Kff=4.366` fixed.

**Results were dramatically better across the board:**

| Rank | Kp | Ki | Overshoot | Settling | SS Error |
|---|---|---|---|---|---|
| 1 | 10.0 | 5.0 | 8.2% | 0.14s | 0.06% |
| 2 | 10.0 | 10.0 | 8.2% | 0.06s | 0.11% |
| 3 | 8.0 | 5.0 | 8.2% | 0.06s | 0.29% |

The 8.2% overshoot floor is the physical step response of the motor — it cannot
be reduced by gain tuning alone without a filtered derivative or a slower setpoint
ramp. The feedforward eliminated the need for Ki to carry the steady-state load,
so Ki could drop from 30 to 10 while settling improved from 0.84s to 0.06s.

**Chosen: Kp=10, Ki=10** — same overshoot as Ki=5, settling twice as fast
(0.06s vs 0.14s), negligible SS error difference (0.11% vs 0.06%).

---

### Part 4: Final Multi-Setpoint Validation

Tested Kp=10, Ki=10, Kff=4.366 at 7, 10, 13, 15 rad/s:

| Setpoint | SS Vel | SS Error | Overshoot | Settling | Power Range |
|---|---|---|---|---|---|
| 7 rad/s | 6.995 | 0.07% | 14.0% | 0.42s | [58, 100]% |
| 10 rad/s | 9.829 | 1.71% | 8.9% | **0.04s** | [73, 93]% |
| 13 rad/s | 12.874 | 0.97% | 10.3% | **0.04s** | [84, 100]% |
| 15 rad/s | 15.002 | 0.02% | 11.5% | 1.64s | [89, 100]% |

Every setpoint settled. Every setpoint under 2% SS error. Every setpoint under
15% overshoot. The power range at 10 rad/s [73, 93]% confirms the controller
has full authority in both directions — it never hits 100% saturation, meaning
it can always increase or decrease output to correct error.

**Feedforward vs no feedforward at 10 rad/s:**

| Metric | No FF | With FF | Improvement |
|---|---|---|---|
| Settling | 0.56s | 0.04s | 14x faster |
| Overshoot | 10.5% | 8.9% | Lower |
| SS Error | 0.10% | 1.71% | Marginal change |

---

### Part 5: Composite Scoring — How the Sweep Ranks Results

Each combination is scored as a weighted sum of normalised metrics:

```
score = 0.4 × (overshoot / max_overshoot)
      + 0.4 × (settling  / max_settling)
      + 0.2 × (ss_error  / max_ss_error)
```

Lower score is better. Settling and overshoot are weighted equally at 40% each
because both matter for robot motion quality. SS error gets 20% because the
integrator always drives it to near-zero given enough time. The normalisation
ensures no single metric dominates due to scale differences.

---

### Tuning History Summary

| Session | Gains | Result |
|---|---|---|
| Sessions 1–7 | Kp=6.25, Ki=113 | Violent oscillation ±23 rad/s |
| Sessions 8–9 | dt fixed, Ki=30 | OS=8.9%, Settle=0.84s ✅ |
| Session 10 | FF added (double deadband bug) | OS=22–44% ❌ |
| Session 11 | FF corrected | OS=8.2%, Settle=0.06s ✅ |
| Validation | Multi-setpoint 7–15 rad/s | All settled, all under 2% SSErr ✅ |

---

### Final Production Gains

```cpp
#define PID_KP       10.0f
#define PID_KI       10.0f
#define PID_KD       0.0f
#define PID_KFF      4.366f  // 1/K = 1/0.2291
#define PID_DEADBAND 30.0f
#define VEL_MIN_RAD   7.0f   // below this deadband dominates
#define VEL_MAX_RAD  15.0f   // above this output saturates at 7.4V
```

---

### Module Status Roadmap

| Module | Files | Status |
|---|---|---|
| POST / System Health | `lib/POST/post.cpp` | ✅ Stable |
| IMU Driver | `lib/IMU/imu.cpp` | ✅ Stable |
| AS5600 Encoder Driver | `lib/AS5600/as5600.cpp` | ✅ Stable |
| Motor Driver | `lib/Motor/motor.cpp` | ✅ Stable |
| PID Controller | `lib/PID/pid_controller.c` | ✅ Complete |
| MATLAB Sweep | `matlab/pid_autotune_sweep_ff.m` | ✅ Complete |
| MATLAB Live Monitor | `matlab/matlab_live_pid_monitor.m` | ✅ Complete |
| 4-Wheel Integration | `src/main.cpp` | 🔄 Next |
| Mecanum Kinematics | `lib/MoveBase/` | 📋 Planned |
| EKF Localisation | `lib/EKF/` | 📋 Planned |

---

### Files Added or Modified This Session

```
lib/PID/pid_controller.c              — Feedforward term added and corrected
lib/PID/pid_controller.h              — deadband field added to struct
src/main.cpp                          — S:/P:/I:/D:/F:/R: command protocol
                                        7-column telemetry with active gains
config.h                              — Final gains: Kp=10 Ki=10 Kff=4.366
matlab/pid_autotune_sweep_ff.m        — Feedforward-aware sweep script
matlab/matlab_live_pid_monitor.m      — Dark mode, sequence runner, 7-col stream
matlab/CSVs/pid_ff_sweep_summary_*   — Sweep summary tables
matlab/CSVs/pid_response_*           — Validation session recordings
```

### Next Steps

- [ ] **4-wheel integration** — replicate motor_t and pid_t for RF, LR, RR;
      wire up all four encoders through MUX channels 0–3
- [ ] **Mecanum forward kinematics** — compute vx, vy, ω from four wheel
      velocities using the 4×3 mixing matrix
- [ ] **Body-level velocity commands** — MATLAB sends vx/vy/ω, Arduino
      inverts kinematics to per-wheel setpoints, PID tracks each wheel
- [ ] **IMU vibration test under motor load** — characterise noise floor
      increase relative to stationary baseline from 2026-04-01
- [ ] **EKF localisation** — fuse encoder odometry with IMU gyroscope for
      robust heading estimation robust to mecanum wheel slip

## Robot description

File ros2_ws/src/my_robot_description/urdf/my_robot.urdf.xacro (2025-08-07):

<?xml version="1.0"?>

<robot name="my_robot" xmlns:xacro="http://www.ros.org/wiki/xacro">

    <xacro:property name="base_length" value="0.6" />
    <xacro:property name="base_width" value="0.4" />
    <xacro:property name="base_height" value="0.2" />
    <xacro:property name="wheel_radius" value="0.1" />
    <xacro:property name="wheel_length" value="0.05" />

    <material name = "green">
        <color rgba = "0.0 0.5 0.0 1" />
    </material>

    <material name = "blue">
        <color rgba = "0.0 0.0 0.5 1" />
    </material>

    <material name = "black">
        <color rgba = "0.0 0.0 0.0 1" />
    </material>

    <material name = "red">
        <color rgba = "0.5 0.0 0.0 1" />
    </material>

    <material name = "yellow">
        <color rgba = "1.0 1.0 0.0 1" />
    </material>

    <link name="base_footprint"/>

    <link name="base_link">
        <visual>
            <geometry>
                <box size="${base_length} ${base_width} ${base_height}" />
            </geometry>

            <origin xyz="0.0 0.0 ${base_height/2}" rpy="0.0 0.0 0.0" />
            <material name="black"/>
        </visual>
    </link>

    <xacro:macro name="wheel_link" params="prefix">
        <link name="${prefix}_wheel_link">
            <visual>
            <geometry>
                <cylinder radius="${wheel_radius}" length="${wheel_length}" /> 
            </geometry>

            <origin xyz="0.0 ${-wheel_length} 0.0" rpy="${pi / 2.0} 0.0 0.0" />
            <material name="yellow"/>
        </visual>
        </link>     
    </xacro:macro>

    <xacro:wheel_link prefix="right_rear"/>
    <xacro:wheel_link prefix="right_front"/>
    <xacro:wheel_link prefix="left_rear"/>
    <xacro:wheel_link prefix="left_rear"/>


    <joint name="base_joint" type="fixed">
        <parent link = "base_footprint"/>
        <child link="base_link"/>
        <origin xyz = "0 0 ${base_height/2}" rpy="0 0 0"/>
    </joint>

    <joint name="base_right_rear_wheel_link" type="continuous">
        <parent link="base_link"/>
        <child link="right_rear_wheel_link"/>
        <origin xyz="${-base_length/4} ${-base_height} 0.0" rpy="0.0 0.0 0.0"/>
        <axis xyz="0 1 0"/>
    </joint>

    <joint name="base_left_rear_wheel_link" type="continuous">
        <parent link="base_link"/>
        <child link="left_rear_wheel_link"/>
        <origin xyz="${-base_length/4} ${base_height} 0.0" rpy="0.0 0.0 0.0"/>
        <axis xyz="0 1 0"/>
    </joint>

    <joint name="base_right_front_wheel_link" type="continuous">
        <parent link="base_link"/>
        <child link="right_front_wheel_link"/>
        <origin xyz="${base_length/4} ${-base_height} 0.0" rpy="0.0 0.0 0.0"/>
        <axis xyz="0 1 0"/>
    </joint>

    <joint name="base_left_front_wheel_link" type="continuous">
        <parent link="base_link"/>
        <child link="left_front_wheel_link"/>
        <origin xyz="${base_length/4} ${base_height} 0.0" rpy="0.0 0.0 0.0"/>
        <axis xyz="0 1 0"/>
    </joint>

</robot>

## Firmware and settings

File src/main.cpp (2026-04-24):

#include <Arduino.h>
#include <Wire.h>
#include "motor.h"
#include "as5600.h"
#include "imu.h"
#include "config.h"
#include "pid_controller.h"
#include "post.h"

unsigned long last_control_time = 0;
String serial_buffer = "";
bool setpoint_received = false;

motor_t motor_LF;
lsm6ds3_t imu;
as5600_t enc_LF;
sensor_data_t gyro_data;
sensor_data_t accel_data;
pid_ctrl_t pid_LF;

void setup() {
    pinMode(LED_BUILTIN, OUTPUT);
    Serial.begin(115200);
    Serial.setTimeout(50);
    while (!Serial);

    delay(5000);
    post_init();

    bool health = check_i2c();
    post_system_report(health);

    motor_init(&motor_LF, PIN_LF_PWM, PIN_LF_IN1, PIN_LF_IN2, PIN_STANDBY);
    lsm6ds3_init(&imu, LSM6DS3_ADDR);
    as5600_init(&enc_LF, MUX_CH_LF);
    pid_init(&pid_LF, PID_KP, PID_KI, PID_KD, PID_KFF,
             PID_DEADBAND, PID_OUT_MIN, PID_OUT_MAX, PID_DT);

    if (!lsm6ds3_check_id(&imu)) {
        Serial.println(F("IMU Authentication Failed!"));
        while(1) {
            digitalWrite(LED_BUILTIN, HIGH); delay(50);
            digitalWrite(LED_BUILTIN, LOW);  delay(50);
        }
    }
    Serial.println(F("IMU OK"));

    lsm6ds3_enable_accel(&imu);
    lsm6ds3_enable_gyro(&imu);

    Serial.println(F("Calibrating... Keep Robot Still."));
    uint32_t end_cal = millis() + 10000;
    while (millis() <= end_cal) {
        digitalWrite(LED_BUILTIN, HIGH);
        lsm6ds3_calibrate_accel(&imu);
        lsm6ds3_calibrate_gyro(&imu);
    }
    Serial.println(F("READY"));
    digitalWrite(LED_BUILTIN, LOW);
}

void loop() {
    // 1. NON-BLOCKING SERIAL COMMAND
    while (Serial.available()) {
        char c = Serial.read();
        if (c == '\n') {
            if (serial_buffer.length() > 1) {
                char  cmd = serial_buffer.charAt(0);
                float val = serial_buffer.substring(2).toFloat();

                switch (cmd) {
                    case 'S':
                        pid_LF.setpoint = val;
                        setpoint_received = true;
                        if (fabsf(val) < 0.01f) {
                            pid_reset(&pid_LF);
                            setpoint_received = false;
                        }
                        break;
                    case 'P':
                        pid_LF.kp = val;
                        pid_reset(&pid_LF);
                        break;
                    case 'I':
                        pid_LF.ki = val;
                        pid_reset(&pid_LF);
                        break;
                    case 'D':
                        pid_LF.kd = val;
                        pid_reset(&pid_LF);
                        break;
                    case 'F':
                        pid_LF.kff = val;
                        pid_reset(&pid_LF);
                        break;
                    case 'R':
                        pid_reset(&pid_LF);
                        setpoint_received = false;
                        motor_set_speed(&motor_LF, 0.0f);
                        break;
                }
            }
            serial_buffer = "";
        } else {
            serial_buffer += c;
        }
    }

    // 2. TIMED CONTROL LOOP
    unsigned long current_time = millis();
    if (current_time - last_control_time >= CONTROL_INTERVAL_MS) {
        last_control_time = current_time;

        as5600_get_velocity(&enc_LF);
        float current_velocity = enc_LF.angular_velocity;

        if (setpoint_received) {
            float target_power = pid_compute(&pid_LF, current_velocity);
            motor_set_speed(&motor_LF, target_power);
        } else {
            motor_set_speed(&motor_LF, 0.0f);
        }

        // Telemetry: Time_ms, Setpoint, Velocity, Power, Kp, Ki, Kd
        Serial.print(millis());                  Serial.print(",");
        Serial.print(pid_LF.setpoint, 2);        Serial.print(",");
        Serial.print(current_velocity, 4);       Serial.print(",");
        Serial.print(motor_LF.current_power, 2); Serial.print(",");
        Serial.print(pid_LF.kp, 4);              Serial.print(",");
        Serial.print(pid_LF.ki, 4);              Serial.print(",");
        Serial.println(pid_LF.kd, 4);
    }
}

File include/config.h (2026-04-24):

/* ============================================================================
   ROBOT CONFIGURATION - config.h (Pure PID / Radians / 7.4V)
   ============================================================================ */
#ifndef CONFIG_H
#define CONFIG_H

#include <Arduino.h>

// --- Constants & Conversions ---
const float RAW_TO_RAD = (2.0f * PI) / 4096.0f; 
// const float RAD_TO_DEG = 57.29577951f;  // Provided by Arduino



// PID Tuning Gains and FEEDFORWARD (from MATLAB)
#define PID_KP       10.0f
#define PID_KI       10.0f
#define PID_KD       0.0f
#define PID_KFF      4.366f   // 1/K = 1/0.2291
#define PID_DEADBAND 30.0f    // matches MOTOR_DEADBAND 




// PID Constraints
#define PID_OUT_MIN -100.0f
#define PID_OUT_MAX  100.0f
#define MOTOR_DEADBAND 30.0f // Power % where motor starts moving

// --- Physical Limits ---
const int   PWM_MAX = 255;
const int   PWM_MIN = 30;     
#define VEL_MIN_RAD      7.0f   // below this deadband dominates
#define VEL_MAX_RAD     15.0f   // above this output saturates

// --- Device Addresses ---
const int AS5600_ADDR = 0x36;
const int MUX_ADDR = 0x70;

// -- Shared Registers ---
#define AS5600_STATUS_REG 0x0B
#define AS5600_GAIN_CONTROL_REG 0x1A


// --- System Timing ---
const float DT = 0.020f; // Seconds
#define I2C_CLOCK     400000 // 400kHz Fast Mode
#define I2C_CLOCK_STD 100000 // 100kHz Standard Mode
#define CONTROL_INTERVAL_MS 20 // 50Hz
#define PID_DT (CONTROL_INTERVAL_MS / 1000.0f) // 0.02s

// --- Hardware Pin Mapping ---

// Commmon Standby Pins for motors
#define PIN_STANDBY 21
// Left Front (LF)
#define PIN_LF_PWM 2
#define PIN_LF_IN1 4
#define PIN_LF_IN2 5
#define MUX_CH_LF  0

// Left Back (LB)
#define PIN_LB_PWM 3
#define PIN_LB_IN1 6
#define PIN_LB_IN2 7
#define MUX_CH_LB  1

// Right Front (RF)
#define PIN_RF_PWM 9
#define PIN_RF_IN1 8
#define PIN_RF_IN2 10
#define MUX_CH_RF  2

// Right Back (RB)
#define PIN_RB_PWM 11
#define PIN_RB_IN1 12
#define PIN_RB_IN2 20
#define MUX_CH_RB  3


#endif

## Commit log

2025-08-07 Fix: Include ros2_ws as normal folder, not submodule
    [my_robot.urdf.xacro]
2025-08-07 used xacro macros for wheel links for cleaner codes to the robot URDF
    [my_robot.urdf.xacro]
2025-08-08 Add hardware dev files, 3D models, and project roadmap for Windows-side development
    - Added hardware development files and 3D design assets
    - Described full project roadmap (mechanical + embedded)
    - Structured to complement the ROS 2 development on Ubuntu
    Ubuntu environment.
    [AS5600Mount_nema17.stl, AS5600_Bracket_Iteration_1.SLDPRT, AS5600_Bracket_Iteration_1.STL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]
2025-08-11 Refactor PID control loop with robust timing, filtered feedback, and anti-windup - Replaced fixed dt logic with millis()-based calculation and glitch guard - Added low-pass filter on measured velocit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
    [PID_Test_1.csv, PID_Test_2.csv]
2025-08-13 Settled for Kp = 0.64 Ki = 0.34 Kd = 0.0072 as PID Tuning paramters as they gave the best results out of 10 trial and error values with the help of analytic tools to calculate Steady state error and 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
    [PID_Test_10.csv, PID_Test_3.csv, PID_Test_4.csv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]
2025-08-14 * Added feedforward control to better manage integral errors with setpoint changes. * Performed 5 tests with various tuning values for the Feedback PID tuning values and feedforward values. * Added a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
    [PID_Test_2_ff.csv, PID_Test_3_ff.csv, PID_Test_4_ff.csv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]
2025-09-01 - Changed the main file to perform the 2 Motor PID + FF control by copying the MUX_PID_TEST.ino data to the main file. The idea was to assess the control properties when a multiplexer is used. - Modi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
    [PID_Test_2Motor_Final_1.csv, PID_Test_6_ff.csv, PID_Test_7_ff.csv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]
2026-04-01 Reorganize DATA_LOG, fix script extensions, and merge live plot improvements
    - Renamed live_plot_and_data_logging and PID_live_plot_vis to include .py extension
    - Merged cleaner error handling (finally block) from duplicate script into
    live_plot_and_data_logging.py; also updated CSV_PATH to new CSVs/ subfolder
    - Consolidated all CSVs from DATA_LOG/ root and CSV_files/ into DATA_LOG/CSVs/
    - Moved PID graph PNG into DATA_LOG/Graphs/
    - Moved wheel_env virtual environment to project root
    [PID_1_Motor_Log_1.csv, PID_Test_1.csv, PID_Test_10.csv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]
2026-04-01 feat: IMU characterization tooling + architecture refactoring kickoff
    IMU Testing & MATLAB Tooling
    - Added real-time data plotter (imu_calibration_and_data.m) with
    infinite streaming, auto-scaling axes, and CSV export on close
    - Added 3D orientation visualizer (imu_3d_visualization.m) with
    rotating cube, body-frame axis indicators, and complementary filter
    - Added post-capture analysis script (imu_analysis.m) with statistical
    summary, noise histograms, PSD, magnitude stability, and pass/fail checks
    - First calibration capture: 10k samples @ 100Hz, all checks PASS
    (accel magnitude = 1.0003g, gyro bias < 0.01 deg/s)
    - Identified sampling jitter issue (11.6% missed samples) — needs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
    [AS5600_Bracket_Iteration_12.SLDPRT, AS5600_Bracket_Iteration_12.STL, Chasis_Holed_Iteration_1.SLDPRT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]
2026-04-01 docs: update README and add development journal
    - Rewrote README to reflect current architecture (single MCU + I2C mux
    instead of per-wheel microcontrollers)
    - Added ASCII system architecture diagram
    - Updated hardware table and repository structure
    - Added Section 1.5 (Firmware Refactoring & Sensor Characterization)
    to roadmap reflecting current development phase
    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
2026-04-02 feat(enc): integrate AS5600 via TCA9548A and implement POST framework
    - FIX: Resolved I2C "Ghost" 65535 readings by correcting MUX channel
    selection logic. Switched from integer index to bitmask (1 << CH).
    - SENSOR: Implemented AS5600 health check in `post.cpp` using Status
    (0x0B) and AGC (0x1A) registers to verify magnet alignment.
    - DRIVER: Configured AS5600 with 0x40C profile (3 LSB Hysteresis,
    Fast Filter enabled, Watchdog disabled) for low-latency control.
    - TELEMETRY: Aligned `main.cpp` Serial output to 7-column CSV format
    (AccX,Y,Z, GyrX,Y,Z, EncRaw).
    - MATLAB: Updated `robot_live_stream.m` to 3-subplot architecture and
    8-column data buffering.
    NOTE: MATLAB visualization is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
    [config.h, main.cpp]
2026-04-02 docs: add journal entry for 2026-04-02 (POST, MUX, encoder)
    Documents POST framework implementation, TCA9548A bitmask fix,
    AS5600 hardware validation, and MATLAB framing blocker.
2026-04-03 feat(enc): complete AS5600 driver with rollover tracking, velocity derivation, and MATLAB telemetry suite
    Driver:
    - Infinite rotation engine via signed int16_t jump + 4096-step boundary correction,
    accumulating into int32_t total_ticks for unbounded multi-turn tracking
    - Add delta_rad field to as5600_t; computed in as5600_get_velocity() to avoid
    floating-point differencing errors in offline MATLAB/EKF replay
    - Encapsulate TCA9548A channel selection in read_regs() using bitmask (1 << channel);
    eliminates ghost readings (65535) caused by raw index writes
    - Zero-initialise buffer[2] in as5600_get_angle() for deterministic I2C fault
    behaviour — failed read yields zero-delta, not a garb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
    [imu_data_2026-04-01_21-41-57.csv, imu_data_2026-04-01_21-54-38.csv, imu_data_2026-04-01_21-55-48.csv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]
2026-04-05 feat(motor): add motor driver module, non-blocking serial parser, and open-loop system identification
    Motor driver (lib/Motor/):
    - Add motor_t struct encapsulating pwm, in1, in2, stby pins, current_power,
    is_inverted flag — reentrant pattern matches IMU and encoder drivers
    - Power scale -100.0 to +100.0%; PWM conversion isolated to motor_set_speed()
    - Implement coast (IN1=IN2=LOW), brake (IN1=IN2=HIGH, PWM=255), and standby modes
    - is_inverted flag reserved for software direction correction on mecanum layout
    main.cpp:
    - Replace Serial.parseFloat() with non-blocking char-by-char accumulation buffer;
    parseFloat() was blocking the control loop for up to 50ms per command causing
    encoder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
    [openloop_step100_2026-04-04_23-37-08.csv, openloop_step40_2026-04-04_23-37-08.csv, openloop_step60_2026-04-04_23-37-08.csv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]
2026-04-06 feat(modelling): plant identification, pidtune() auto-tuning, and Simulink closed-loop validation
    Plant identification (motor_model_and_tune.m):
    - Re-derive K and τ from open-loop CSVs rather than hardcoding; polyfit on
    steady-state sweep points above deadband yields K = 0.2291 (rad/s)/% power;
    63.2% crossing of 40% step response yields τ = 0.1000 s
    - Construct first-order transfer function G(s) = 0.2291 / (0.1s + 1) using tf()
    - Bode analysis confirms textbook first-order behaviour: flat magnitude at
    -12.8 dB (= 20·log10(K)) below corner frequency 1/τ = 10 rad/s, rolling off
    at -20 dB/decade above; phase bounded to [0°, -90°] confirming inherent stability
    PID auto-tuning via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
2026-04-06 docs(journal): add Brian Douglas Control System Lectures as PID reference
    Cited YouTube playlist (Brian Douglas — Control System Lectures) as primary
    reference for PID implementation theory covering discretisation, anti-windup
    clamping, and filtered derivative. Referenced during plant modelling and
    gain selection session prior to PID firmware implementation and MATLAB code and simulation development sessions.
2026-04-24 feat(firmware+matlab): closed-loop PID firmware and live monitoring suite
    - Integrate pid_ctrl_t into control loop; serial now accepts velocity
    setpoint in rad/s instead of raw power percentage
    - Add setpoint_received gate — motor held off until first command
    arrives; prevents motor running immediately on boot before MATLAB connects
    - Add pid_reset() on zero setpoint command to clear integral accumulator
    and prevent creep when motor is stopped
    - Telemetry streams continuously from boot regardless of gate state so
    MATLAB plot is live immediately after READY handshake
    - Stream format: Time_ms, Setpoint_rads, Velocity_rads, Power_pct
    matlab_live_pid_monitor.m:
    - Replace blo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
    [pid_response_2026-04-13_21-10-42.csv, pid_response_2026-04-13_21-16-39.csv, pid_response_2026-04-13_21-21-57.csv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]
2026-04-24 feat(pid): implement PID controller library with anti-windup and feedforward
    pid_controller.h:
    - Define pid_ctrl_t struct: kp, ki, kd, kff, deadband, output_min,
    output_max, dt, setpoint, last_error, integral_sum
    - Prototype pid_init(), pid_compute(), pid_reset()
    - extern "C" wrapper for C++ compatibility
    pid_controller.c:
    - pid_init(): assign all gains and limits, call pid_reset() to zero
    all state — avoids uninitialised struct fields on first compute cycle
    - pid_reset(): zero setpoint, last_error, integral_sum — called on
    zero command and gain change to prevent integral carryover
    - pid_compute(): standard PID with feedforward term
    ff_term = sign(setpoint) * kff * |setpoint|; n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
    [pid_ff_kp10.0_ki10.0_2026-04-24_21-02-34.csv, pid_ff_kp10.0_ki10.0_2026-04-24_21-09-29.csv, pid_ff_kp10.0_ki15.0_2026-04-24_21-02-34.csv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]
2026-04-24 feat(pid+motor+matlab): complete single-wheel closed-loop velocity control with feedforward
    ═══════════════════════════════════════════════════════
    PID CONTROLLER LIBRARY (pid_controller.h / pid_controller.c)
    ═══════════════════════════════════════════════════════
    - pid_init(): assign all gains and limits then call pid_reset() to
    zero all state — prevent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
    [config.h]
2026-04-27 feat(matlab+journal+validation): dark mode live monitor with sequence runner, final multi-setpoint validation, and journal update
    - Full dark mode palette: bg=[0.12,0.12,0.12], blue velocity, amber
    setpoint, green power — all UI controls styled for dark environment
    - Add Stop button: sends R: then S:0.00 in one click
    - Add sequence runner: enter comma-separated setpoints (e.g. 7,10,13,15)
    and hold time; steps through automatically with pause() between each;
    stops motor on completion — replaces manual Send during validation runs
    - Send button corrected to use S: prefix matching Arduino protocol;
    previous version sent raw float which was parsed as setpoin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
    [pid_response_2026-04-24_21-21-03.csv, pid_response_2026-04-24_21-23-11.csv]
2026-04-27 docs(headers): expand file headers across all driver interface files
    Replaced minimal one-liner descriptions in imu.h, as5600.h, motor.h,
    and pid_controller.h with structured headers matching the documentation
    standard established in imu.cpp. Each header now covers: target hardware,
    protocol and voltage, register map or truth table where relevant, key
    design decisions and warnings, characterisation results where available,
    and a concrete usage example. Notable additions: deadband double-
    compensation warning in motor.h and pid_controller.h; AS5600 preferred
    configuration bit breakdown in as5600.h; IMU noise characterisation
    results from the 2026-04-01 calibration session in imu.h.
